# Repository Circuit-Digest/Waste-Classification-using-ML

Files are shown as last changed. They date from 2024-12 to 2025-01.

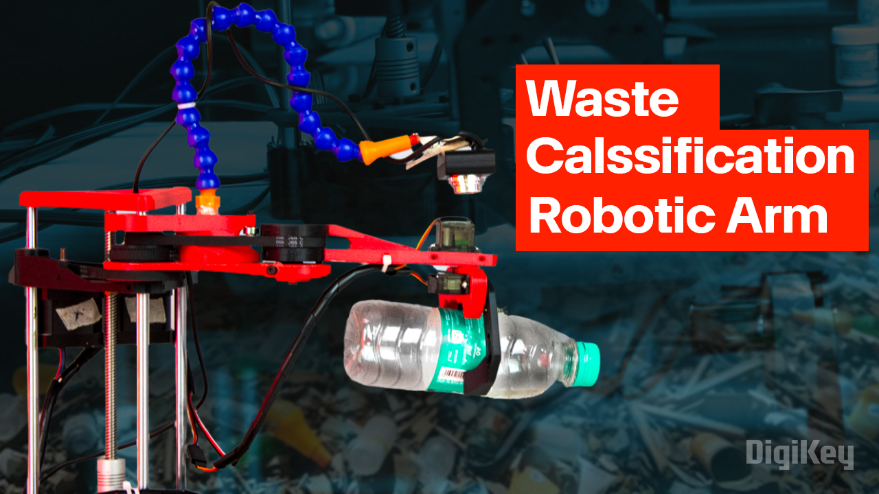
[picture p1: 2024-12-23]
Artboard 2.jpg

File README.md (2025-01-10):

# [Waste Classification Using Machine Learning and SCARA Robotic Arm](https://circuitdigest.com/videos/waste-classification-using-machine-learning-and-scara-robotic-arm)
Artboard 2

Waste Classification Using Machine Learning and SCARA Robotic Arm
This project introduces an innovative solution to automate waste segregation using a SCARA Robot enhanced with computer vision and machine learning. The project used a pre-deployed AI model to classify the objects into organic or inorganic waste. At its core, the project utilises a Raspberry Pi paired with a USB camera to capture images of waste materials, this captured image is then processed with the help of inference SDK and the Roboflow waste classification API. Once classified, the robotic arm, controlled by an ESP32-C6 WROOM module, handles the waste, placing it into designated bins. This integration of robotics and artificial intelligence not only enhances automation but also contributes to effective waste management solutions.

The SCARA robot retains its compact and precise design, featuring NEMA 17 stepper motors powered by TMC2209 drivers for smooth operation, alongside SG90S servo motors for precise gripper control. The robust power system includes an LM2596-5 buck converter and an ADP7118AUJZ-3.3 LDO, ensuring the reliable operation of the ESP32-C6 and its peripherals. The Raspberry Pi handles image capture, and ML inferencing, leveraging the RoboFlow platform API for real-time inference. A Python-based control script on the Raspberry Pi seamlessly interfaces with the ESP32-C6 via serial communication to coordinate waste classification and robotic arm movements. This project exemplifies the potential of combining robotics and AI to solve real-world challenges. It provides a hands-on platform for exploring automation, embedded systems, and machine learning applications.

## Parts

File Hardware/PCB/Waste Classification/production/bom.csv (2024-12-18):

Designator | Footprint | Quantity | Value | LCSC Part #
C1, C2 | CAP_J-V_10X10P5_RUB | 2 | 330uF
C10, C5 | 0805 | 2 | 10uF
C11, C7, C8, C9 | 0603 | 4 | 0.1uF
C3 | 0603 | 1 | 2.2uF
C4 | 0603 | 1 | NC
D1, D3 | D_SMA | 2 | SS34
D2 | 0805 | 1 | LED
IC1 | SOT95P280X100-5N | 1 | ADP7118AUJZ-3.3-R7
J1 | TerminalBlock_Phoenix_PT-1,5-2-5.0-H_1x02_P5.00mm_Horizontal | 1 | Screw_Terminal_2_P5.00mm
J10, J4, J6, J8 | PinHeader_2x03_P2.54mm_Vertical | 4 | Conn_02x03_Top_Bottom
J11, J5, J7, J9 | JST_XH_B4B-XH-AM_1x04_P2.50mm_Vertical | 4 | Conn_01x04
J12, J13, J14, J15, J16 | JST_XH_B3B-XH-AM_1x03_P2.50mm_Vertical | 5 | Conn_01x03
J17 | JST_EH_B4B-EH-A_1x04_P2.50mm_Vertical | 1 | Conn_01x04
J2 | BarrelJack_Kycon_KLDX-0202-xC_Horizontal | 1 | Barrel_Jack_Switch
J3 | USB_C_Receptacle_HRO_TYPE-C-31-M-12 | 1 | USB_C_Receptacle_USB2.0
L1 | L_12x12mm_H8mm | 1 | 47uH
LED1 | 150505M173300 | 1 | 150505M173300
R1 | 0603 | 1 | 0
R10, R11, R12, R13, R14, R15, R16, R17, R6, R7, R8 | 0603 | 11 | 1K
R18, R19, R2, R20, R21, R4, R5, R9 | 0603 | 8 | 10K
R3 | 0603 | 1 | 47K
SW1 | Tactile 3x4x2mm TS-A010 | 1 | RST
SW2 | Tactile 3x4x2mm TS-A010 | 1 | BOOT
U1 | TO-263-5_TabPin3 | 1 | LM2596S-5
U2 | MAX6899AAZT+T | 1 | MAX6899AAZT+T
U3 | ESP32-C6-WROOM-1 | 1 | ESP32-C6-WROOM-1
U4, U5, U6, U7 | MODULE_TMC2209_SILENTSTEPSTICK | 4 | TMC2209_SILENTSTEPSTICK

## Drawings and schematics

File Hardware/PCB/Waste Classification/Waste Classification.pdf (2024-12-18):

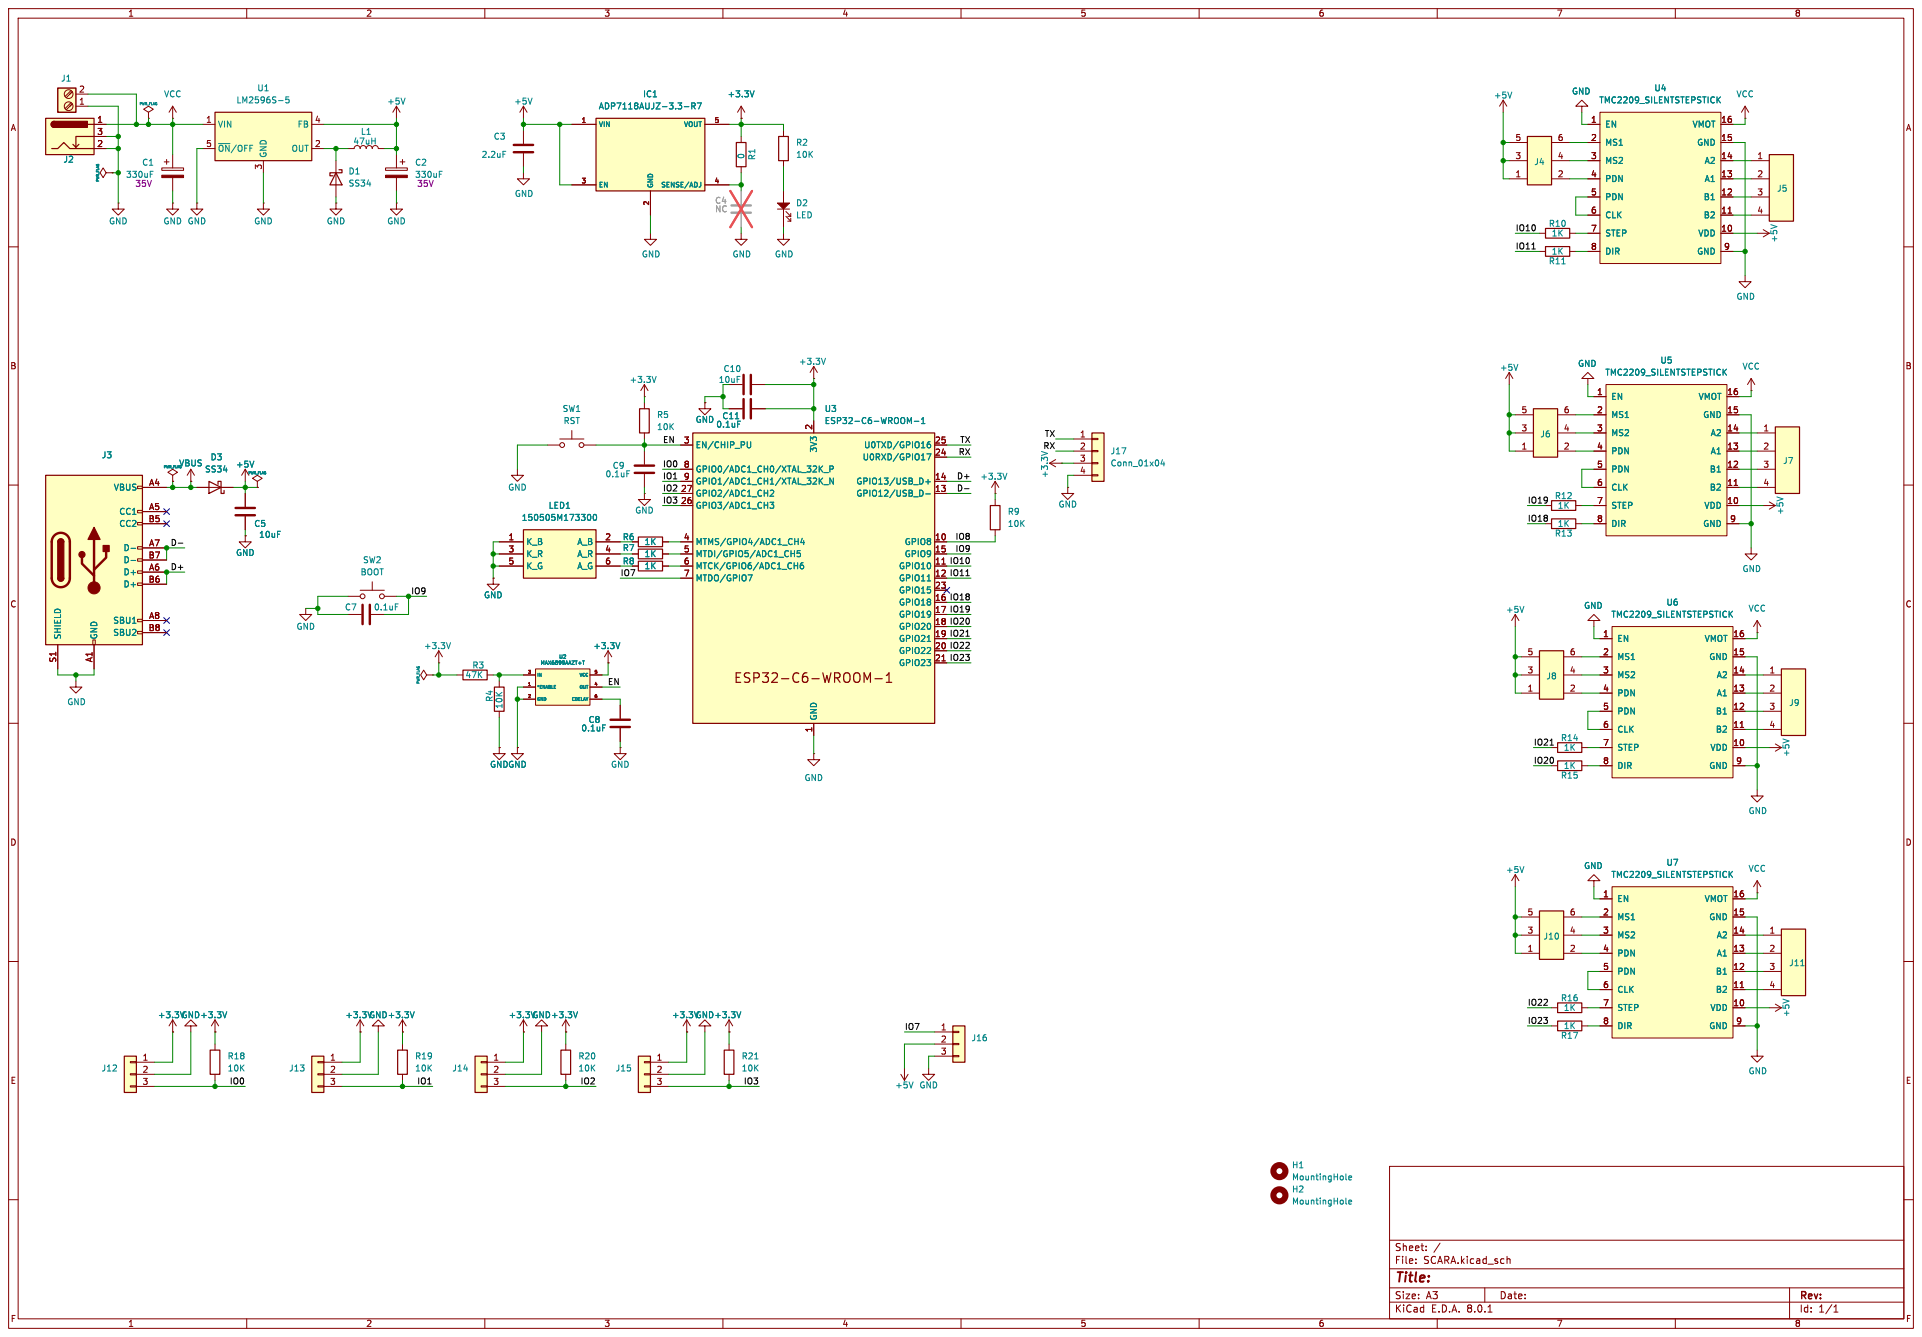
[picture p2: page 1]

2 EN 3 SENSE/ADJ 4 VOUT 5

2 EN 3 SENSE/ADJ 4 VOUT 5C4 NC

2 GPIO22 20 GPIO23 21 GPIO15 23 U0RXD/GPIO17 24 U0TXD/GPIO16 25 GPIO3/ADC1_CH3 26 GPIO2/ADC1_CH2 27 EN/CHIP_PU 3 MTMS/GPIO4/ADC1_CH4 4 MTDI/GPIO5/ADC1_CH5 5 MTCK/GPIO6/ADC1_CH6 6 MTDO/GPIO7 7 GPIO0/ADC1_CH0/XTAL_32K_P 8 GPIO1/ADC1_CH1/XTAL_32K_N 9 U3ESP32-C6-WROOM-1 C11

2 GPIO22 20 GPIO23 21 GPIO15 23 U0RXD/GPIO17 24 U0TXD/GPIO16 25 GPIO3/ADC1_CH3 26 GPIO2/ADC1_CH2 27 EN/CHIP_PU 3 MTMS/GPIO4/ADC1_CH4 4 MTDI/GPIO5/ADC1_CH5 5 MTCK/GPIO6/ADC1_CH6 6 MTDO/GPIO7 7 GPIO0/ADC1_CH0/XTAL_32K_P 8 GPIO1/ADC1_CH1/XTAL_32K_N 9 GND

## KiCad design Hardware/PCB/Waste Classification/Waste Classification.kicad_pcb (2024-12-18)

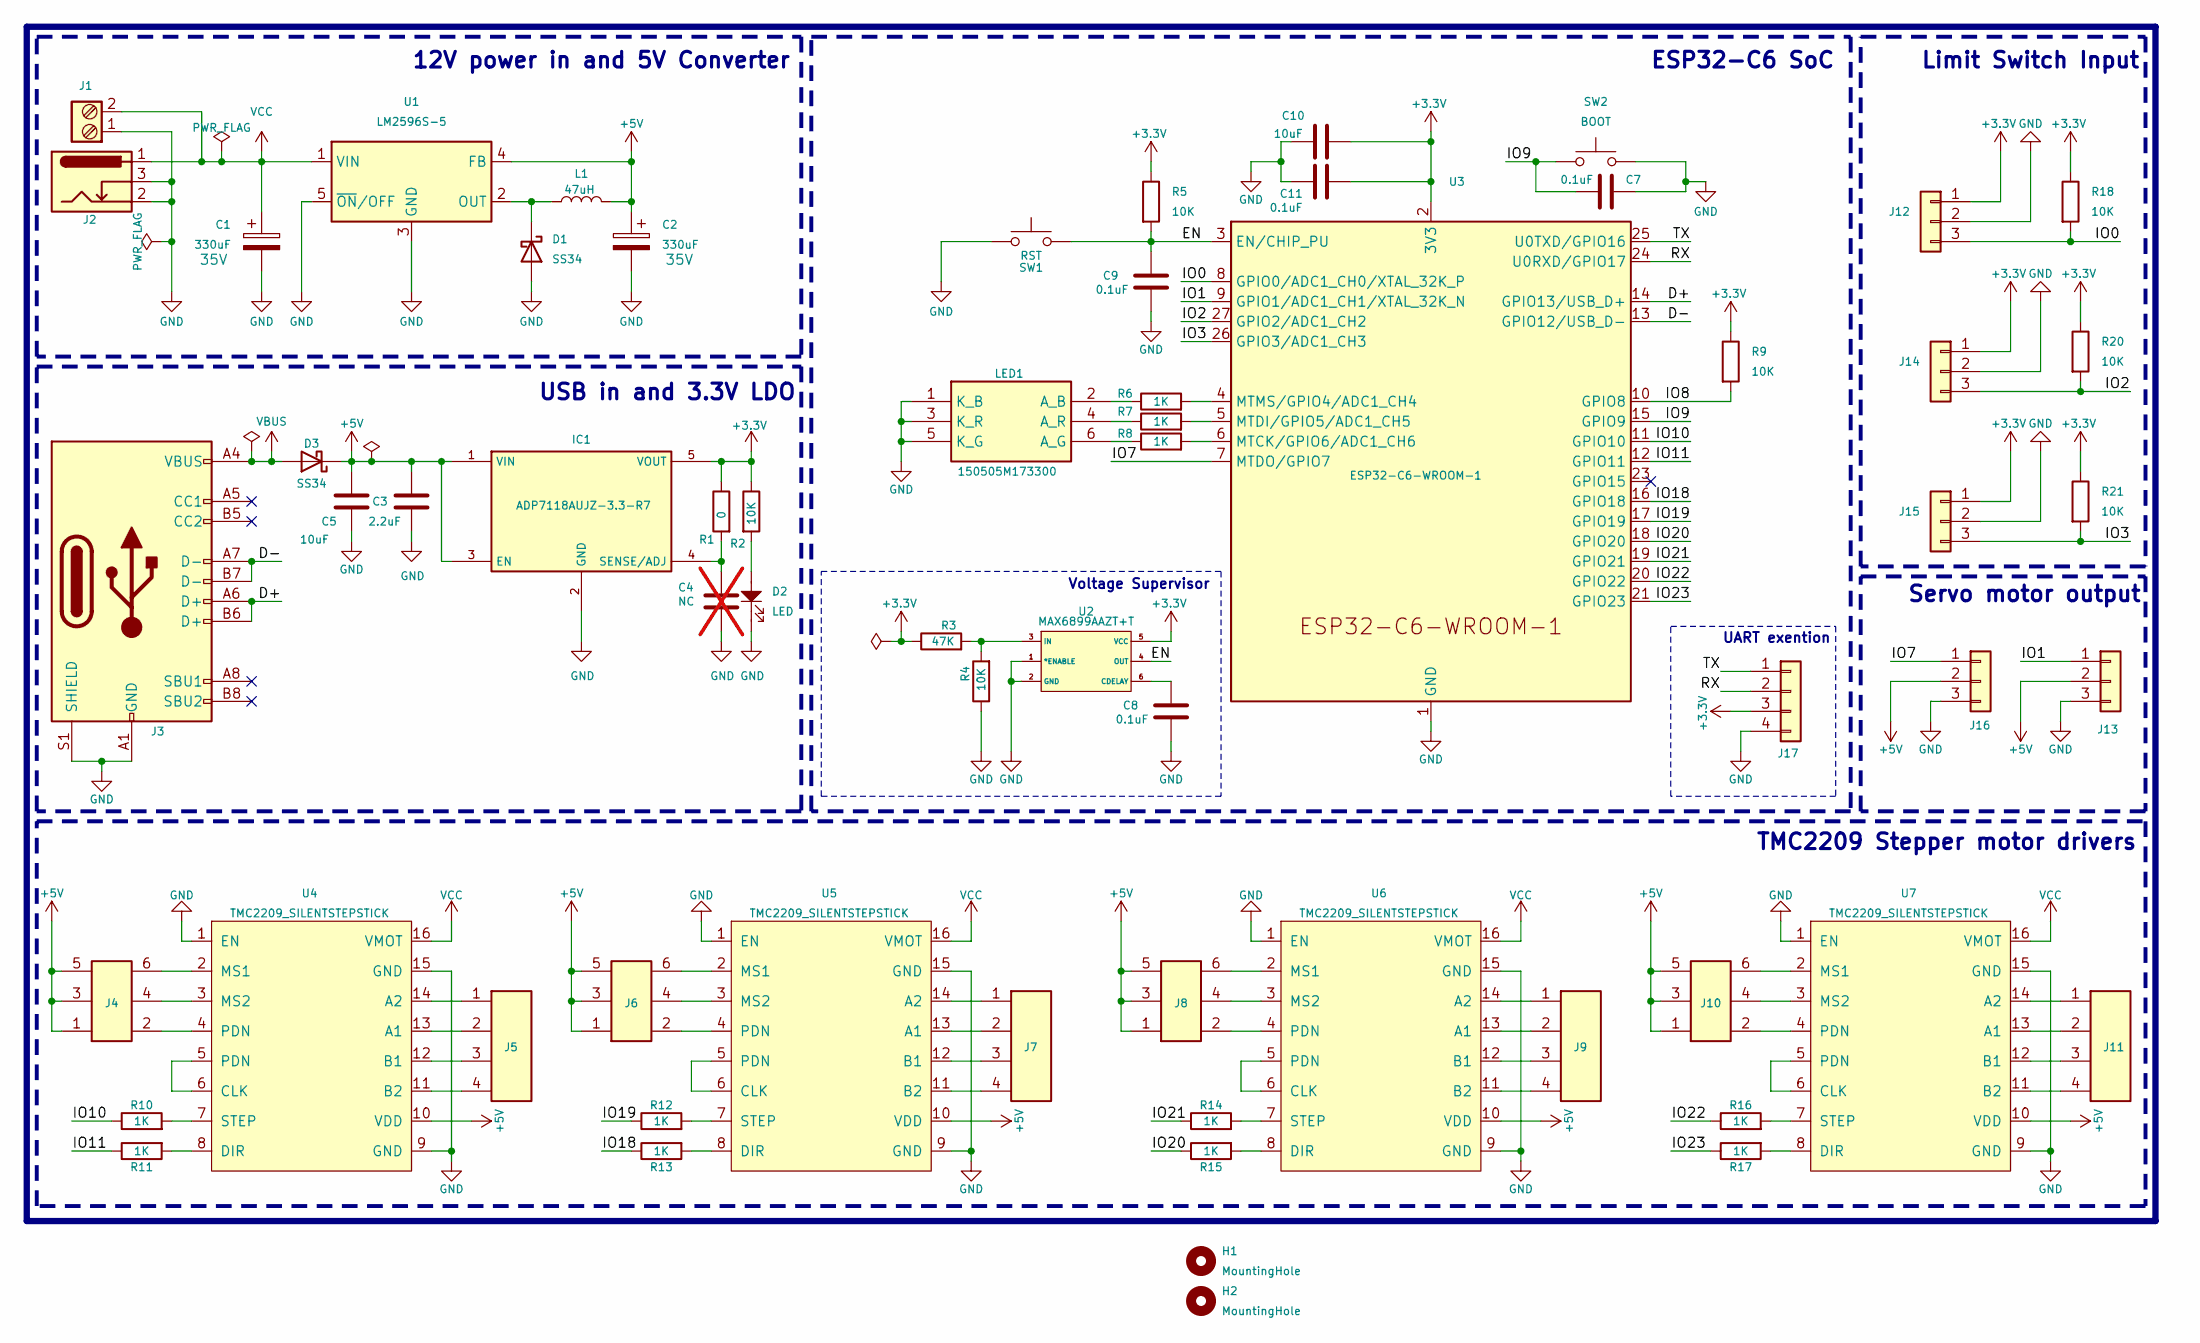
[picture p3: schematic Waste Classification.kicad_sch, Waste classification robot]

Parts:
C1, C2: 330uF; CAP_J-V_10X10P5_RUB; Voltage 35V
C3: 2.2uF; C_0603_1608Metric
C4: NC; C_0603_1608Metric; not fitted
C5, C10: 10uF; C_0805_2012Metric
C7, C8, C9, C11: 0.1uF; C_0603_1608Metric
D1, D3: SS34; D_SMA
D2: LED; LED_0805_2012Metric
H1, H2: MountingHole; MountingHole_2.2mm_M2_Pad
IC1: ADP7118AUJZ-3.3-R7; SOT95P280X100-5N; Mouser Part Number 584-ADP7118AUJZ3.3R7
J1: Screw_Terminal_2_P5.00mm; TerminalBlock_Phoenix_PT-1,5-2-5.0-H_1x02_P5.00mm_Horizontal
J2: Barrel_Jack_Switch; BarrelJack_Kycon_KLDX-0202-xC_Horizontal
J3: USB_C_Receptacle_USB2.0; USB_C_Receptacle_HRO_TYPE-C-31-M-12
J4, J6, J8, J10: Conn_02x03_Top_Bottom; PinHeader_2x03_P2.54mm_Vertical
J5, J7, J9, J11: Conn_01x04; JST_XH_B4B-XH-AM_1x04_P2.50mm_Vertical
J12, J13, J14, J15, J16: Conn_01x03; JST_XH_B3B-XH-AM_1x03_P2.50mm_Vertical
J17: Conn_01x04; JST_EH_B4B-EH-A_1x04_P2.50mm_Vertical
L1: 47uH; L_12x12mm_H8mm
LED1: 150505M173300; Mouser Part Number 710-150505M173300
R1: 0; R_0603_1608Metric
R2, R4, R5, R9, R18, R20, R21: 10K; R_0603_1608Metric
R3: 47K; R_0603_1608Metric
R6, R7, R8, R10, R11, R12, R13, R14, R15, R16, R17: 1K; R_0603_1608Metric
SW1: RST; Tactile 3x4x2mm TS-A010
SW2: BOOT; Tactile 3x4x2mm TS-A010
U1: LM2596S-5; TO-263-5_TabPin3
U2: MAX6899AAZT+T
U3: ESP32-C6-WROOM-1
U4, U5, U6, U7: TMC2209_SILENTSTEPSTICK; MODULE_TMC2209_SILENTSTEPSTICK

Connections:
+3.3V: C10.1, C11.1, IC1.5 (VOUT), J12.1, J14.1, J15.1, J17.3, R1.1, R2.1, R3.1, R5.1, R9.1, R18.1, R20.1, R21.1, U2.5 (VCC), U3.2 (3V3)
+5V: C2.1, C3.1, C5.1, D3.1 (K), IC1.1 (VIN), IC1.3 (EN), J4.1, J4.3, J4.5, J6.1, J6.3, J6.5, J8.1, J8.3, J8.5, J10.1, J10.3, J10.5, J13.2, J16.2, L1.2, U1.4 (FB), U4.10 (VDD), U5.10 (VDD), U6.10 (VDD), U7.10 (VDD)
/D+: J3.A6 (D+), J3.B6 (D+), U3.14 (GPIO13/USB_D+)
/D-: J3.A7 (D-), J3.B7 (D-), U3.13 (GPIO12/USB_D-)
/EN: C9.1, R5.2, SW1.2, U2.4 (OUT), U3.3 (EN/CHIP_PU)
/IO0: J12.3, R18.2, U3.8 (GPIO0/ADC1_CH0/XTAL_32K_P)
/IO1: J13.1, U3.9 (GPIO1/ADC1_CH1/XTAL_32K_N)
/IO2: J14.3, R20.2, U3.27 (GPIO2/ADC1_CH2)
/IO3: J15.3, R21.2, U3.26 (GPIO3/ADC1_CH3)
/IO7: J16.1, U3.7 (MTDO/GPIO7)
/IO8: R9.2, U3.10 (GPIO8)
/IO9: C7.2, SW2.2, U3.15 (GPIO9)
/IO10: R10.1, U3.11 (GPIO10)
/IO11: R11.1, U3.12 (GPIO11)
/IO18: R13.1, U3.16 (GPIO18)
/IO19: R12.1, U3.17 (GPIO19)
/IO20: R15.1, U3.18 (GPIO20)
/IO21: R14.1, U3.19 (GPIO21)
/IO22: R16.1, U3.20 (GPIO22)
/IO23: R17.1, U3.21 (GPIO23)
/RX: J17.2, U3.24 (U0RXD/GPIO17)
/TX: J17.1, U3.25 (U0TXD/GPIO16)
GND: C1.2, C2.2, C3.2, C4.2, C5.2, C7.1, C8.2, C9.2, C10.2, C11.2, D1.2 (A), D2.1, IC1.2 (GND), J1.1, J2.2, J2.3, J3.A1 (GND), J3.A12 (GND), J3.B1 (GND), J3.B12 (GND), J3.S1 (SHIELD), J12.2, J13.3, J14.2, J15.2, J16.3, J17.4, LED1.1 (K_B), LED1.3 (K_R), LED1.5 (K_G), R4.1, SW1.1, SW2.1, U1.3 (GND), U1.5 (~ON/OFF), U2.1 (*ENABLE), U2.2 (GND), U3.1 (GND), U3.28 (GND), U3.29 (GND), U4.1 (EN), U4.9 (GND), U4.15 (GND), U5.1 (EN), U5.9 (GND), U5.15 (GND), U6.1 (EN), U6.9 (GND), U6.15 (GND), U7.1 (EN), U7.9 (GND), U7.15 (GND)
unnamed: D1.1 (K), L1.1, U1.2 (OUT)
unnamed: D2.2, R2.2
unnamed: C4.1, IC1.4 (SENSE/ADJ), R1.2
unnamed: J4.2, U4.4 (PDN)
unnamed: J4.4, U4.3 (MS2)
unnamed: J4.6, U4.2 (MS1)
unnamed: J5.1, U4.14 (A2)
unnamed: J5.2, U4.13 (A1)
unnamed: J5.3, U4.12 (B1)
unnamed: J5.4, U4.11 (B2)
unnamed: J6.2, U5.4 (PDN)
unnamed: J6.4, U5.3 (MS2)
unnamed: J6.6, U5.2 (MS1)
unnamed: J7.1, U5.14 (A2)
unnamed: J7.2, U5.13 (A1)
unnamed: J7.3, U5.12 (B1)
unnamed: J7.4, U5.11 (B2)
unnamed: J8.2, U6.4 (PDN)
unnamed: J8.4, U6.3 (MS2)
unnamed: J8.6, U6.2 (MS1)
unnamed: J9.1, U6.14 (A2)
unnamed: J9.2, U6.13 (A1)
unnamed: J9.3, U6.12 (B1)
unnamed: J9.4, U6.11 (B2)
unnamed: J10.2, U7.4 (PDN)
unnamed: J10.4, U7.3 (MS2)
unnamed: J10.6, U7.2 (MS1)
unnamed: J11.1, U7.14 (A2)
unnamed: J11.2, U7.13 (A1)
unnamed: J11.3, U7.12 (B1)
unnamed: J11.4, U7.11 (B2)
unnamed: LED1.2 (A_B), R6.1
unnamed: LED1.6 (A_G), R8.1
unnamed: LED1.4 (A_R), R7.1
unnamed: C8.1, U2.6 (CDELAY)
unnamed: R3.2, R4.2, U2.3 (IN)
unnamed: R8.2, U3.6 (MTCK/GPIO6/ADC1_CH6)
unnamed: R7.2, U3.5 (MTDI/GPIO5/ADC1_CH5)
unnamed: R6.2, U3.4 (MTMS/GPIO4/ADC1_CH4)
unnamed: U4.5 (PDN), U4.6 (CLK)
unnamed: R11.2, U4.8 (DIR)
unnamed: R10.2, U4.7 (STEP)
unnamed: U5.5 (PDN), U5.6 (CLK)
unnamed: R13.2, U5.8 (DIR)
unnamed: R12.2, U5.7 (STEP)
unnamed: U6.5 (PDN), U6.6 (CLK)
unnamed: R15.2, U6.8 (DIR)
unnamed: R14.2, U6.7 (STEP)
unnamed: U7.5 (PDN), U7.6 (CLK)
unnamed: R17.2, U7.8 (DIR)
unnamed: R16.2, U7.7 (STEP)
VBUS: D3.2 (A), J3.A4 (VBUS), J3.A9 (VBUS), J3.B4 (VBUS), J3.B9 (VBUS)
VCC: C1.1, J1.2, J2.1, U1.1 (VIN), U4.16 (VMOT), U5.16 (VMOT), U6.16 (VMOT), U7.16 (VMOT)

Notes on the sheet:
USB in and 3.3V LDO
UART exention
TMC2209 Stepper motor drivers
ESP32-C6 SoC
Voltage Supervisor
12V power in and 5V Converter
Servo motor output
Limit Switch Input

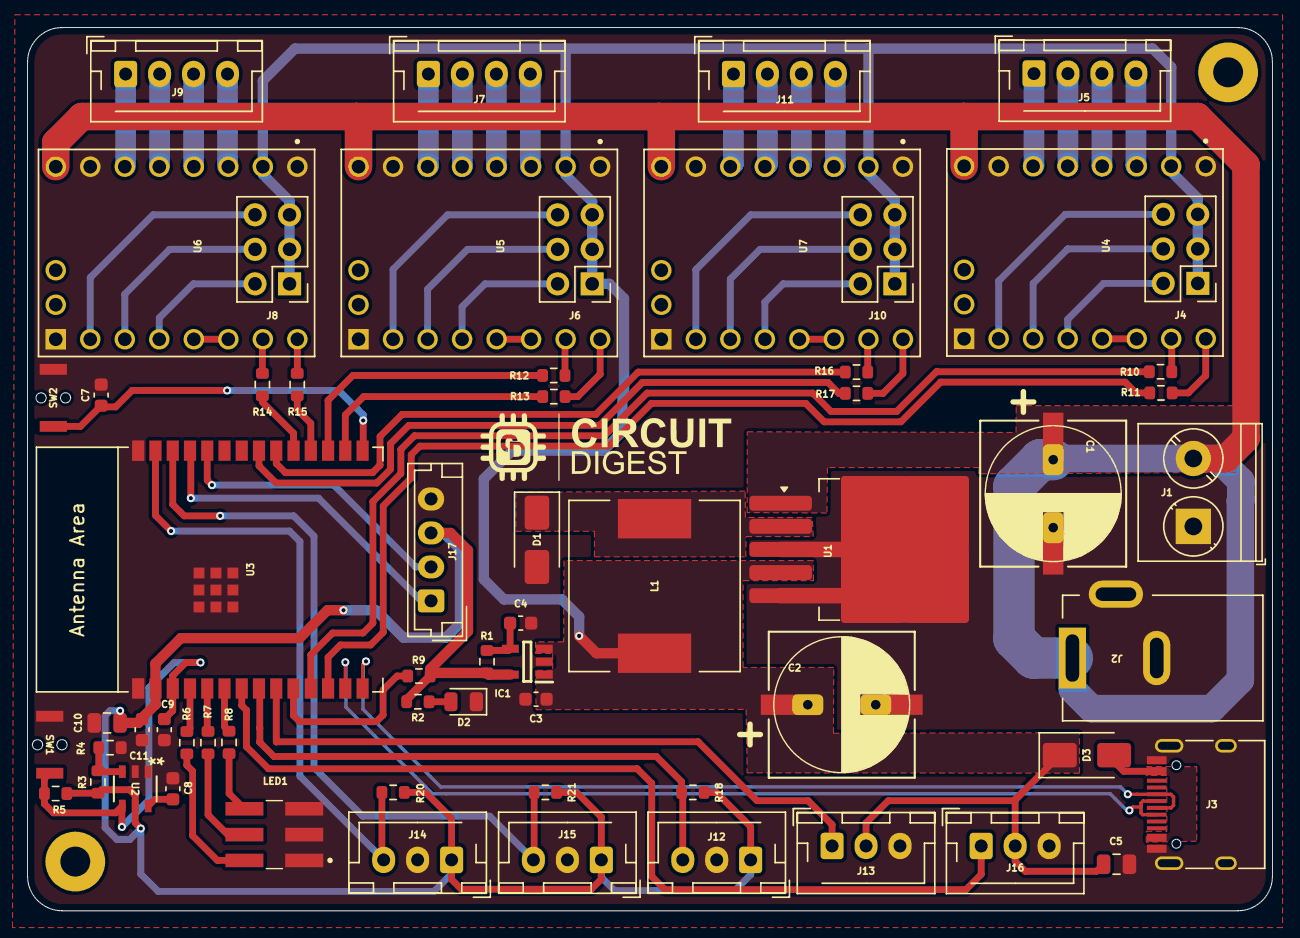
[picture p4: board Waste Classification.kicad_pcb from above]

Board: 2 copper layers, 91.6 x 65.0 mm, 64 parts (0 on the bottom side), 76 nets.

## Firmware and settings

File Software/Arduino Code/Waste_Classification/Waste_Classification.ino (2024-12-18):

#include <AccelStepper.h>
#include <ESP32Servo.h>

#define GRIPPER_PIN 7  // Pin for the servo controlling the gripper
#define WRIST_PIN 1    // Pin for the servo controlling wrist rotation

// Define the stepper motors and the pins they will use
AccelStepper stepper1(1, 21, 20); // (Type:driver, STEP, DIR)
AccelStepper stepper2(1, 19, 18);
AccelStepper stepper3(1, 22, 23);

Servo gripperServo;  // create servo object to control a servo
Servo wristServo;    // Servo object for the wrist rotation

const float theta1AngleToSteps = 14.55;  // Conversion factor for theta1
const float theta2AngleToSteps = 11.43;  // Conversion factor for theta2
const float zAngleToSteps = 400;         // Conversion factor for phi
const int gripperCloseAngle = 140;
const int gripperOpenAngle = 80;

//int initialise = 0;

void setup() {
    Serial.begin(115200); // USB communication for debugging
    // Stepper motors max speed and acceleration
    stepper1.setMaxSpeed(4000);
    stepper1.setAcceleration(2000);
    stepper2.setMaxSpeed(4000);
    stepper2.setAcceleration(2000);
    stepper3.setMaxSpeed(4000);
    stepper3.setAcceleration(2000);

    gripperServo.attach(GRIPPER_PIN);
    gripperServo.write(gripperOpenAngle); // Open gripper by default

    wristServo.attach(WRIST_PIN); // Pin for wrist control
    wristServo.write(61); // Default wrist angle*/
}

String ID = "NULL";

void loop() {   
    if (Serial.available()) {
        String command = Serial.readStringUntil('\n');
        command.trim();
        if (command == "BIODEGRADABLE" || command == "PAPER" || command == "CLOTH")
        ID = "organic";
        if (command == "CARDBOARD" || command == "GLASS" || command == "METAL" || command == "PLASTIC")
        ID = "inorganic";
        executeCommand(ID);

        ID = "NULL";
    }   
}

void executeCommand(String ID) {
  
    //pick up the organic object and drop command
    if(ID.equalsIgnoreCase("organic")){
        moveToPosition(0,510,-70);      
        gripperServo.write(gripperCloseAngle); // Close gripper
        moveToPosition(0,510,0);  
        moveToPosition(-120,0,0);   //before moveToPosition(150,500,-70);
        gripperServo.write(gripperOpenAngle); // Open gripper
       
        moveToPosition(0,0,0); //HOME POSITION FOR ORGANIC 
      //clear serial buffer
      while(Serial.available()){
        Serial.read(); //read and discard anything in buffer
      }  
      Serial.println("READY");
    }

    //pick up the in-organic object and drop command
    else if(ID.equalsIgnoreCase("inorganic")){
      moveToPosition(0,510,-70);      
      gripperServo.write(gripperCloseAngle); // Close gripper
      moveToPosition(0,510,0);
      moveToPosition(120,1020,0);   //before moveToPosition(150,500,-70);
      gripperServo.write(gripperOpenAngle); // Open gripper 

      moveToPosition(0,1020,0);  //home position for in-organic
      //clear serial buffer
      while(Serial.available()){
        Serial.read(); //read and discard anything in buffer
      }
      Serial.println("READY");       
    }
    
    // Unknown command
    else {
        Serial.println("Unknown command");
    }
}

// Function to move to position
void moveToPosition(int x, int y, int z) {
  
    stepper1.moveTo(x * theta1AngleToSteps);
    stepper2.moveTo(y * theta2AngleToSteps);
    stepper3.moveTo(z * zAngleToSteps);
    
    while (stepper1.isRunning() || stepper2.isRunning() || stepper3.isRunning()) {
        stepper1.run();
        stepper2.run();
        stepper3.run();
    }
}

void setGripperZ(int gripperZ){
    wristServo.write(gripperZ); // Set wrist position
}

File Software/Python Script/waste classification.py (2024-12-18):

import cv2
from inference_sdk import InferenceHTTPClient
import serial
import time  # Import time module to add delays

# Configure the serial connection
ser = serial.Serial('/dev/ttyACM0', baudrate=115200)
print("Press Enter to capture a frame or 'q' to exit the live camera feed.")

# Initialize the webcam
cap = cv2.VideoCapture(0)

if not cap.isOpened():
    print("Error: Unable to access the webcam.")
    exit()

# Initialize the InferenceHTTPClient
CLIENT = InferenceHTTPClient(
    api_url="https://detect.roboflow.com",
    api_key="iEtMvLxXrAR7cF9eFdTV"
)

last_label = ""  # To store the last label value that was sent to serial
inference_in_progress = False  # Flag to track if inference is in progress

try:
    while True:
        # Read the current frame from the camera
        ret, frame = cap.read()

        if not ret:
            print("Error: Unable to capture an image from the webcam.")
            continue

        # Show the live camera feed
        cv2.imshow("Live Camera Feed", frame)

        # Check for keyboard input for capturing a frame
        key = cv2.waitKey(1) & 0xFF  # Wait for a key press
        if key == ord('q'):  # Press 'q' to quit
            break
        elif key == 13 and not inference_in_progress:  # Press Enter to capture a frame (if no inference is in progress)
            print("Capturing frame and sending for inference...")

            # Set the flag to indicate that inference is in progress
            inference_in_progress = True

            # Send the current frame for inference
            result = CLIENT.infer(frame, model_id="garbage-classification-3/2")

            # Parse the inference result
            predictions = result.get('predictions', [])

            if predictions:
                # Find the prediction with the highest confidence
                best_prediction = max(predictions, key=lambda pred: pred['confidence'])
                x = int(best_prediction['x'])
                y = int(best_prediction['y'])
                width = int(best_prediction['width'])
                height = int(best_prediction['height'])
                label = best_prediction['class']
                confidence = best_prediction['confidence']

                # Calculate top-left and bottom-right coordinates
                top_left = (x - width // 2, y - height // 2)
                bottom_right = (x + width // 2, y + height // 2)

                # Draw the bounding box and label on the frame
                cv2.rectangle(frame, top_left, bottom_right, (0, 255, 0), 2)
                label_text = f"{label} ({confidence:.2f})"
                cv2.putText(frame, label_text, (top_left[0], top_left[1] - 10),
                            cv2.FONT_HERSHEY_SIMPLEX, 0.5, (0, 255, 0), 1)

                # Display the result in the console
                print(f"Detected: {label}, Confidence: {confidence:.2f}, Bounding Box: [{x}, {y}, {width}, {height}]")

                # Send the label value to the serial port if it's not the same as the last sent
                if label != last_label:
                    last_label = label
                    ser.write(f"{label}\n".encode())
            else:
                print("No predictions made.")

            # Add a short delay to avoid sending too many requests
            time.sleep(1)  # 1 second delay before allowing the next inference

            # Reset the flag after the inference is done
            inference_in_progress = False

except KeyboardInterrupt:
    print("\nExiting...")

# Release the resources
cap.release()
cv2.destroyAllWindows()
ser.close()
